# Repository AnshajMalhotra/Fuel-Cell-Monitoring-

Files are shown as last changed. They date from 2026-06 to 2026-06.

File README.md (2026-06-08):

# Project Seminar SS2025 — Fuel Cell Monitoring Board







A mixed-signal hardware and firmware project for monitoring fuel-cell voltage and current using a custom KiCad PCB, precision analog front-end, isolated SPI data path, 16-bit ADC acquisition, and ESP32-S3 based data processing.

This repository combines the complete PCB design files and embedded firmware developed for the **Project Seminar SS2025**. The board is intended to acquire fuel-cell electrical measurements, convert raw ADC data into physical voltage/current values, and stream the processed measurements to a host system over serial communication.

---

## Repository Description

**Short GitHub description:**

> KiCad + ESP32-S3 fuel-cell monitoring board with precision voltage/current sensing, 16-bit SPI ADC acquisition, digital isolation, and PlatformIO firmware for averaged serial data output.

---

## Project Overview

The project focuses on designing and implementing a fuel-cell monitoring board that can measure:

- Fuel-cell voltage
- Fuel-cell current
- ADC raw measurement values
- Averaged and calibrated output data

The system is built around a modular PCB design with separate schematic blocks for power, voltage measurement, current measurement, ADC conversion, data transmission, and microcontroller-side processing.

```mermaid
flowchart LR
    A[Fuel Cell Input] --> B[Voltage Measurement Stage]
    A --> C[Current Measurement Stage]
    B --> D[16-bit ADC]
    C --> D
    D --> E[Digital Isolation / SPI Interface]
    E --> F[ESP32-S3 Firmware]
    F --> G[Serial Output to Host]
```

---

## Key Features

- Custom PCB designed in **KiCad**
- Modular schematic structure for easier debugging and documentation
- Fuel-cell voltage sensing using a resistor divider and analog signal conditioning
- Fuel-cell current sensing using a shunt resistor and current-sense amplifier stage
- Precision voltage reference for ADC conversion
- SPI-based ADC communication
- Digital isolation for safer data transmission between analog and digital domains
- ESP32-S3 firmware using **PlatformIO** and the **Arduino framework**
- Timer-based sampling and averaging for stable readings
- Serial output in a simple host-readable format

---

## Hardware Architecture

| Block | Purpose | Related Files |
|---|---|---|
| Main KiCad Project | Central project configuration | `Project_Seminar_SS2025.kicad_pro` |
| PCB Layout | Physical board layout | `Project_Seminar_SS2025.kicad_pcb` |
| Root Schematic | Top-level schematic project | `Project_Seminar_SS2025.kicad_sch` |
| Power Supply | Power regulation and supply rails | `power.kicad_sch` |
| Voltage Measurement | Fuel-cell voltage sensing stage | `voltage_measure.kicad_sch`, `voltage_mea.kicad_sch` |
| Current Measurement | Shunt/current-sense stage | `current_measure.kicad_sch` |
| ADC Stage | ADC interface and analog conversion | `adc.kicad_sch`, `ADC_Main.kicad_sch` |
| Data Transmission | Isolated SPI / digital communication | `Data_Transmission_Main.kicad_sch` |
| Custom Symbols | Project-specific schematic symbols | `KiCad_Board_Design/MySymbols/` |
| Custom Footprints | Project-specific PCB footprints | `KiCad_Board_Design/MyFootprints/` |
| ERC Report | Electrical rules check output | `ERC.rpt` |

---

## Main Components Used

The design includes footprints/symbols for several important mixed-signal and embedded components, including:

- **ESP32-S3 DevKitC-1** — microcontroller and firmware execution platform
- **LTC2368IMS-16** — 16-bit ADC interface stage
- **LTC6655 4.096 V reference** — precision ADC reference
- **AD8410** — current-sense amplifier stage
- **LT6202** — analog signal conditioning / amplifier stage
- **ADuM4150BRIZ** — digital isolator for SPI communication
- **LT1761 / LT1762** — low-noise voltage regulators
- Custom connectors, jumpers, shunt resistor, and measurement terminals

---

## Firmware Overview

Firmware is located in:

```text
Board_Software/Fuel_Cell/
```

The ESP32-S3 firmware performs the following tasks:

1. Initializes serial communication at `115200 baud`
2. Configures SPI pins for ADC communication
3. Uses a hardware timer for periodic acquisition
4. Reads two 16-bit ADC channels from a 32-bit SPI transfer
5. Averages multiple samples for smoother measurements
6. Converts raw ADC values into voltage and current
7. Sends formatted readings to the host PC

### Firmware Pin Mapping

| Signal | ESP32-S3 Pin |
|---|---:|
| MOSI | GPIO 11 |
| MISO | GPIO 13 |
| SCK | GPIO 12 |
| SS / CS | GPIO 10 |
| CNV | GPIO 14 |
| BUSY | GPIO 9 |

### Serial Output Format

The firmware prints measurements in the following format:

```text
V:12.345,I:1.234
```

Where:

- `V` = calculated fuel-cell voltage in volts
- `I` = calculated fuel-cell current in amperes

---

## Measurement Conversion Logic

The firmware uses a 4.096 V ADC reference and 16-bit conversion range.

### Voltage Conversion

```cpp
adcInputVoltage = (rawValue / 65535.0) * 4.096;
fuelCellVoltage = adcInputVoltage * dividerRatio;
```

The voltage divider ratio is calculated from:

```cpp
R_TOTAL = 39000 + 2000;
R_BOTTOM = 3900 + 100;
dividerRatio = R_TOTAL / R_BOTTOM;
```

### Current Conversion

```cpp
senseAmpOutputVoltage = (rawValue / 65535.0) * 4.096;
shuntVoltage = senseAmpOutputVoltage / 20.0;
fuelCellCurrent = shuntVoltage / 0.008;
```

The current calculation depends on:

- Sense amplifier gain: `20`
- Shunt resistance used in firmware: `0.008 Ω`

> Update these constants if the final measured resistor values or amplifier gain differ from the prototype assumptions.

---

## Getting Started

### 1. Clone the Repository

```bash
git clone https://github.com/<your-username>/<your-repo-name>.git
cd <your-repo-name>
```

### 2. Open the PCB Design

Open the project file in KiCad:

```text
Project_Seminar_SS2025.kicad_pro
```

Recommended KiCad workflow:

1. Open the project in KiCad
2. Review the schematic hierarchy
3. Run ERC from the schematic editor
4. Open the PCB layout
5. Run DRC before manufacturing
6. Generate Gerber/drill files if the board is ready for fabrication

---

## Building and Uploading Firmware

### Prerequisites

Install:

- Visual Studio Code
- PlatformIO extension
- ESP32-S3 board support through PlatformIO
- USB driver for the ESP32-S3 board, if required

### Build Firmware

```bash
cd Board_Software/Fuel_Cell
pio run
```

### Upload Firmware

```bash
pio run --target upload
```

### Open Serial Monitor

```bash
pio device monitor -b 115200
```

Expected output:

```text
Fuel Cell Monitoring Board - Initializing...
Initialization Complete. Starting Data Acquisition.
V:12.345,I:1.234
```

---

## Repository Structure

```text
Project_Seminar_SS2025/
├── Project_Seminar_SS2025.kicad_pro       # Main KiCad project
├── Project_Seminar_SS2025.kicad_sch       # Top-level schematic
├── Project_Seminar_SS2025.kicad_pcb       # PCB layout
├── power.kicad_sch                        # Power supply design
├── current_measure.kicad_sch              # Current measurement circuit
├── voltage_measure.kicad_sch              # Voltage reference / measurement circuit
├── adc.kicad_sch                          # ADC schematic block
├── Data_Transmission_Main.kicad_sch       # Data transmission / isolation block
├── KiCad_Board_Design/
│   ├── MySymbols/                         # Custom KiCad symbols
│   └── MyFootprints/                      # Custom KiCad footprints
└── Board_Software/
    └── Fuel_Cell/
        ├── platformio.ini                 # PlatformIO configuration
        └── src/
            └── main.cpp                   # ESP32-S3 firmware
```

---

## Suggested GitHub Topics

Use these topics on GitHub to make the project easier to discover:

```text
kicad
pcb-design
esp32-s3
platformio
embedded-systems
fuel-cell
adc
spi
current-sensing
voltage-measurement
mixed-signal
arduino-framework
```

---

## Recommended Cleanup Before Publishing

Before pushing to GitHub, avoid committing generated or temporary files such as:

```text
.pio/
build/
*.bin
*.elf
*.map
*.o
*.d
*.bak
*.lck
Project_Seminar_SS2025-backups/
```

A cleaner repository will be smaller, easier to clone, and more professional for reviewers.

---

## Future Improvements

- Add calibration procedure for voltage and current measurements
- Add CSV logging or USB serial data parser on the host side
- Add OLED/display support for live local readings
- Add wireless transmission using Wi-Fi or BLE
- Add automated firmware tests for conversion functions
- Add final board render, schematic screenshots, and measurement results
- Generate Gerber files and attach manufacturing notes

---

## Author

**Anshaj Malhotra**  
M.Eng. Electrical and Information Engineering  
Hochschule Wismar

---

## License

No license has been selected yet. If this project is intended to be open-source, add a license such as MIT, Apache-2.0, or CERN-OHL depending on how you want others to use the hardware and software design.

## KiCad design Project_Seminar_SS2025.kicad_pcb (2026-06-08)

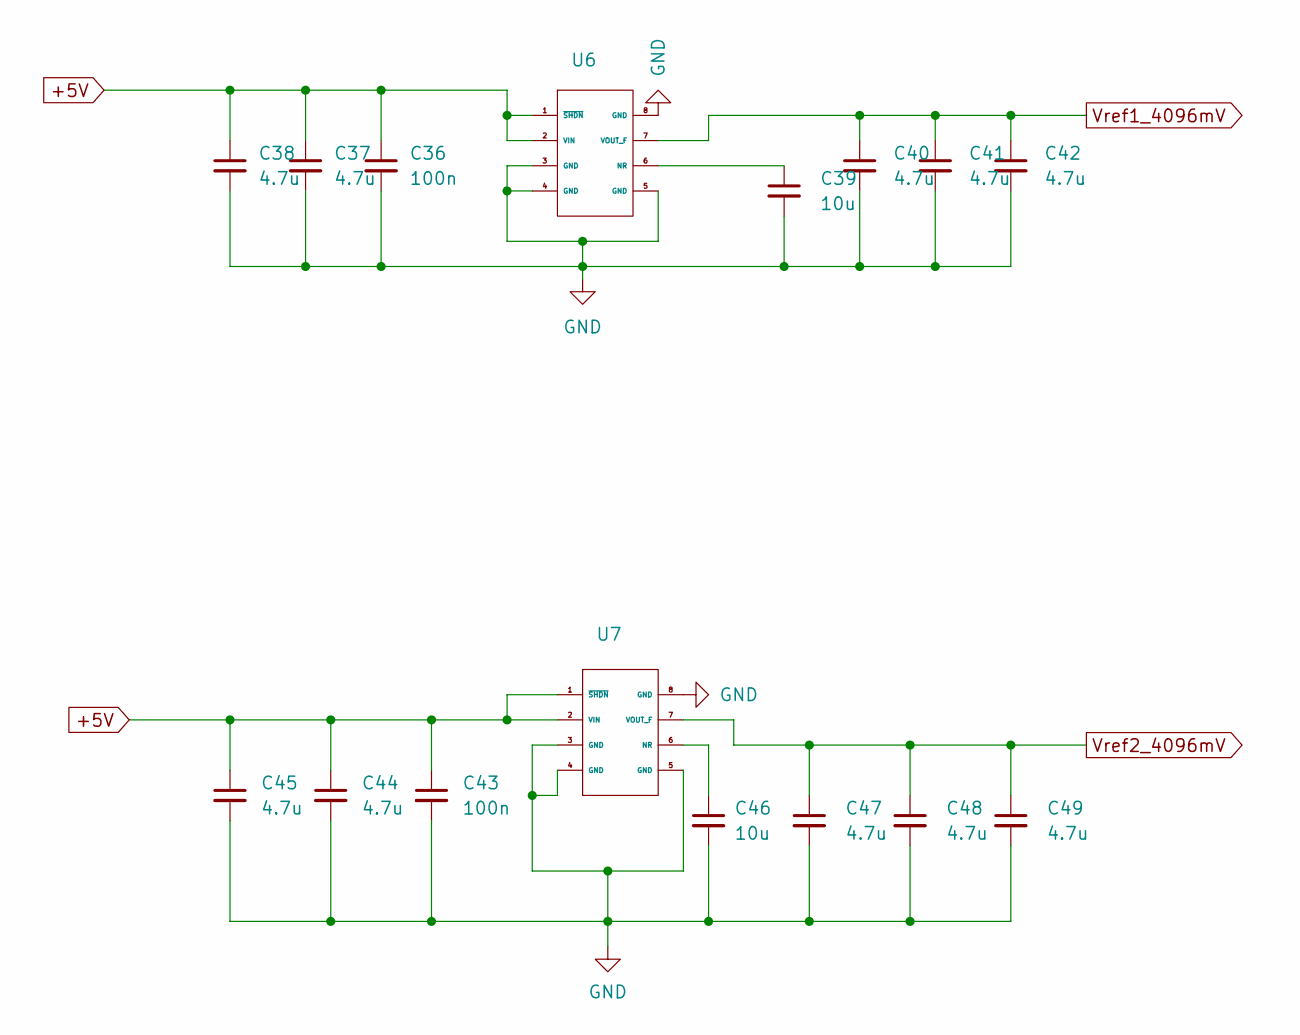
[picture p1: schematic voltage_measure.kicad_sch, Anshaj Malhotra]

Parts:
C36, C43: 100n; C_0201_0603Metric
C37, C38, C40, C41, C42, C44, C45, C47, C48, C49: 4.7u; C_0201_0603Metric
C39, C46: 10u; C_0201_0603Metric
U6, U7: LTC6655LNCHMS8-4.096#PBF

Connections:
+5V: C36.1, C37.1, C38.1, C43.1, C44.1, C45.1, U6.1 (~SHDN), U6.2 (VIN), U7.1 (~SHDN), U7.2 (VIN); also elsewhere on the board
GND: C36.2, C37.2, C38.2, C39.2, C40.2, C41.2, C42.2, C43.2, C44.2, C45.2, C46.2, C47.2, C48.2, C49.2, U6.3 (GND), U6.4 (GND), U6.5 (GND), U6.8 (GND), U7.3 (GND), U7.4 (GND), U7.5 (GND), U7.8 (GND); also elsewhere on the board
unnamed: C39.1, U6.6 (NR)
unnamed: C46.1, U7.6 (NR)
Vref1_4096mV: C40.1, C41.1, C42.1, U6.7 (VOUT_F); also elsewhere on the board
Vref2_4096mV: C47.1, C48.1, C49.1, U7.7 (VOUT_F); also elsewhere on the board

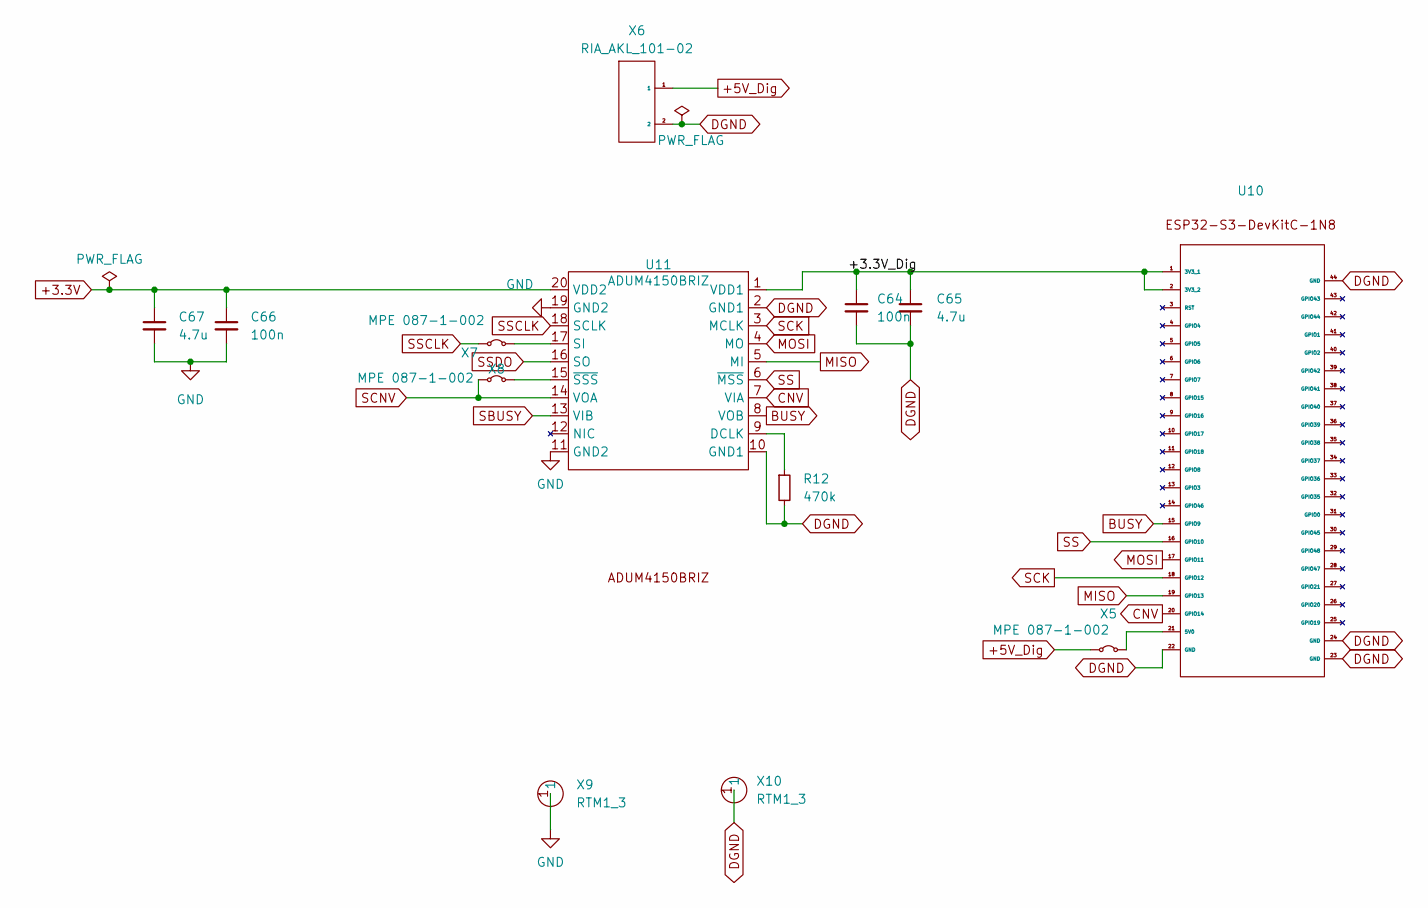
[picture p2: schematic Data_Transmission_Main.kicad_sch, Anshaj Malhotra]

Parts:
C64, C66: 100n; C_0201_0603Metric
C65, C67: 4.7u; C_0201_0603Metric
R12: 470k; R_0402_1005Metric
U10: ESP32
U11: ADUM4150BRIZ
X5, X7, X8: MPE 087-1-002; SolderJumper-2_P1.3mm_Bridged2Bar_Pad1.0x1.5mm
X6: RIA_AKL_101-02; AKL073-2
X9, X10: RTM1_3

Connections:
+3.3V: C66.1, C67.1, U11.20 (VDD2); also elsewhere on the board
+5V_Dig: X5.1 (A), X6.1
/Data transmission/+3.3V_Dig: C64.1, C65.1, U10.1 (3V3_1), U10.2 (3V3_2), U11.1 (VDD1)
BUSY: U10.15 (GPIO9), U11.8 (VOB)
CNV: U10.20 (GPIO14), U11.7 (VIA)
DGND: C64.2, C65.2, R12.2, U10.22 (GND), U10.23 (GND), U10.24 (GND), U10.44 (GND), U11.2 (GND1), U11.10 (GND1), X6.2, X10.1
GND: C66.2, C67.2, U11.11 (GND2), U11.19 (GND2), X9.1; also elsewhere on the board
MISO: U10.19 (GPIO13), U11.5 (MI)
MOSI: U10.17 (GPIO11), U11.4 (MO)
unnamed: U10.21 (5V0), X5.2 (B)
unnamed: R12.1, U11.9 (DCLK)
unnamed: U11.17 (SI), X7.2 (B)
unnamed: U11.15 (~SSS), X8.2 (B)
SBUSY: U11.13 (VIB); also elsewhere on the board
SCK: U10.18 (GPIO12), U11.3 (MCLK)
SCNV: U11.14 (VOA), X8.1 (A)
SS: U10.16 (GPIO10), U11.6 (~MSS)
SSCLK: U11.18 (SCLK), X7.1 (A)
SSDO: U11.16 (SO); also elsewhere on the board

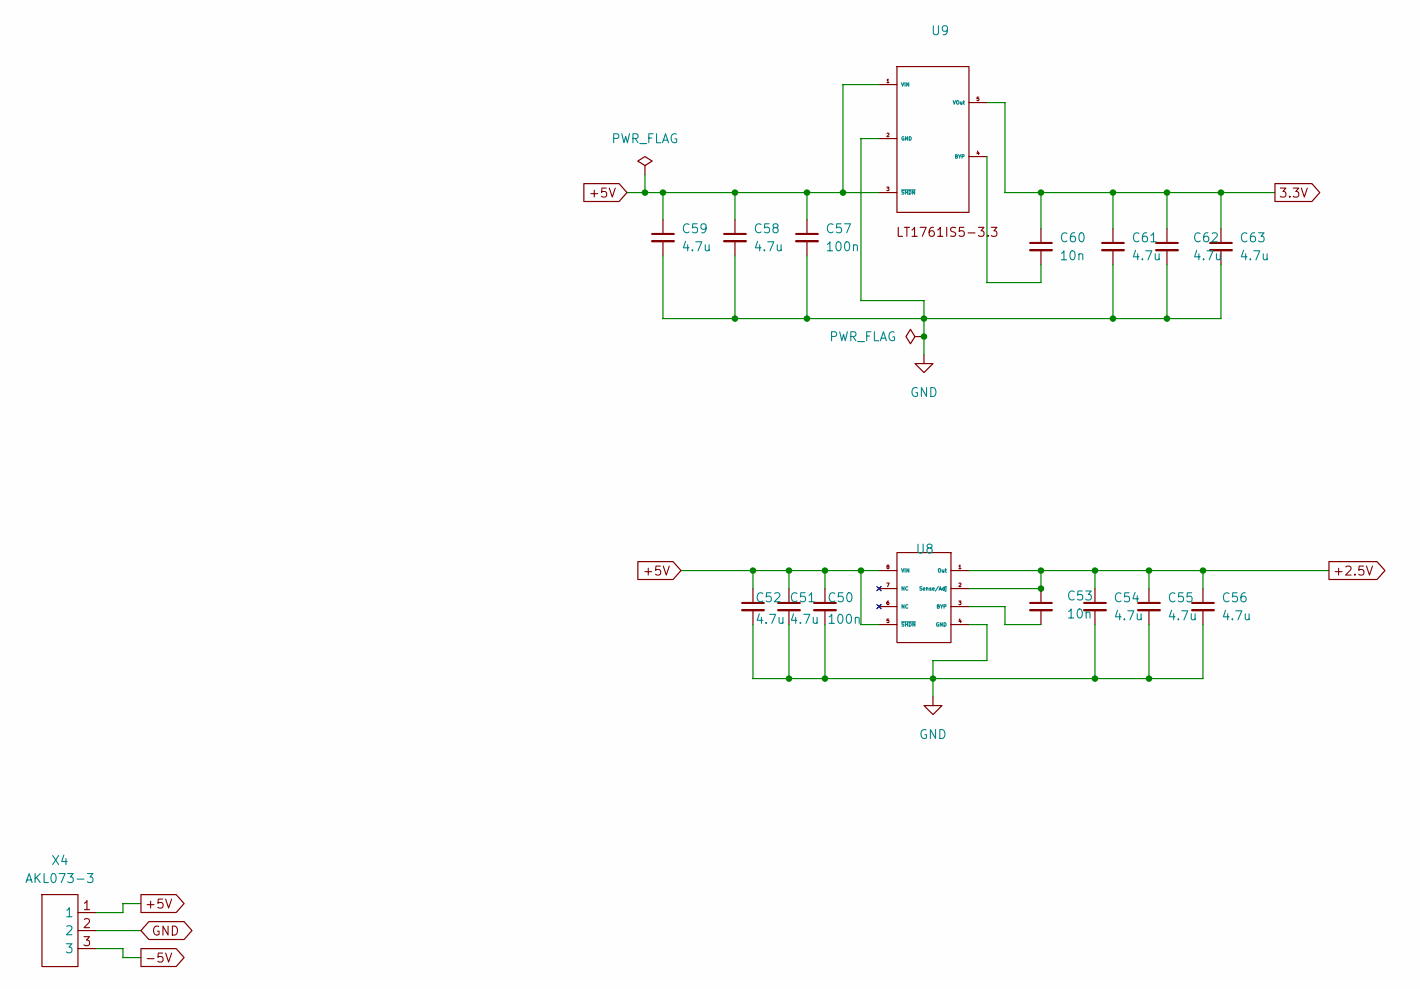
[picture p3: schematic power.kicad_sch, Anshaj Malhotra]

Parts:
C50, C57: 100n; C_0201_0603Metric
C51, C52, C54, C55, C56, C58, C59, C61, C62, C63: 4.7u; C_0201_0603Metric
C53, C60: 10n; C_0402_1005Metric
U8: LT1762EMS8-2v5
U9: LT1761IS5-3.3TRMPBF
X4: AKL073-3; Connector (AKL073-3)

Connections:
3.3V: C60.1, C61.1, C62.1, C63.1, U9.5 (VOut)
+2.5V: C53.1, C54.1, C55.1, C56.1, U8.1 (Out), U8.2 (Sense/Adj); also elsewhere on the board
+5V: C50.1, C51.1, C52.1, C57.1, C58.1, C59.1, U8.5 (~SHDN), U8.8 (VIN), U9.1 (VIN), U9.3 (~SHDN), X4.1; also elsewhere on the board
-5V: X4.3; also elsewhere on the board
GND: C50.2, C51.2, C52.2, C54.2, C55.2, C56.2, C57.2, C58.2, C59.2, C61.2, C62.2, C63.2, U8.4 (GND), U9.2 (GND), X4.2; also elsewhere on the board
unnamed: C53.2, U8.3 (BYP)
unnamed: C60.2, U9.4 (BYP)

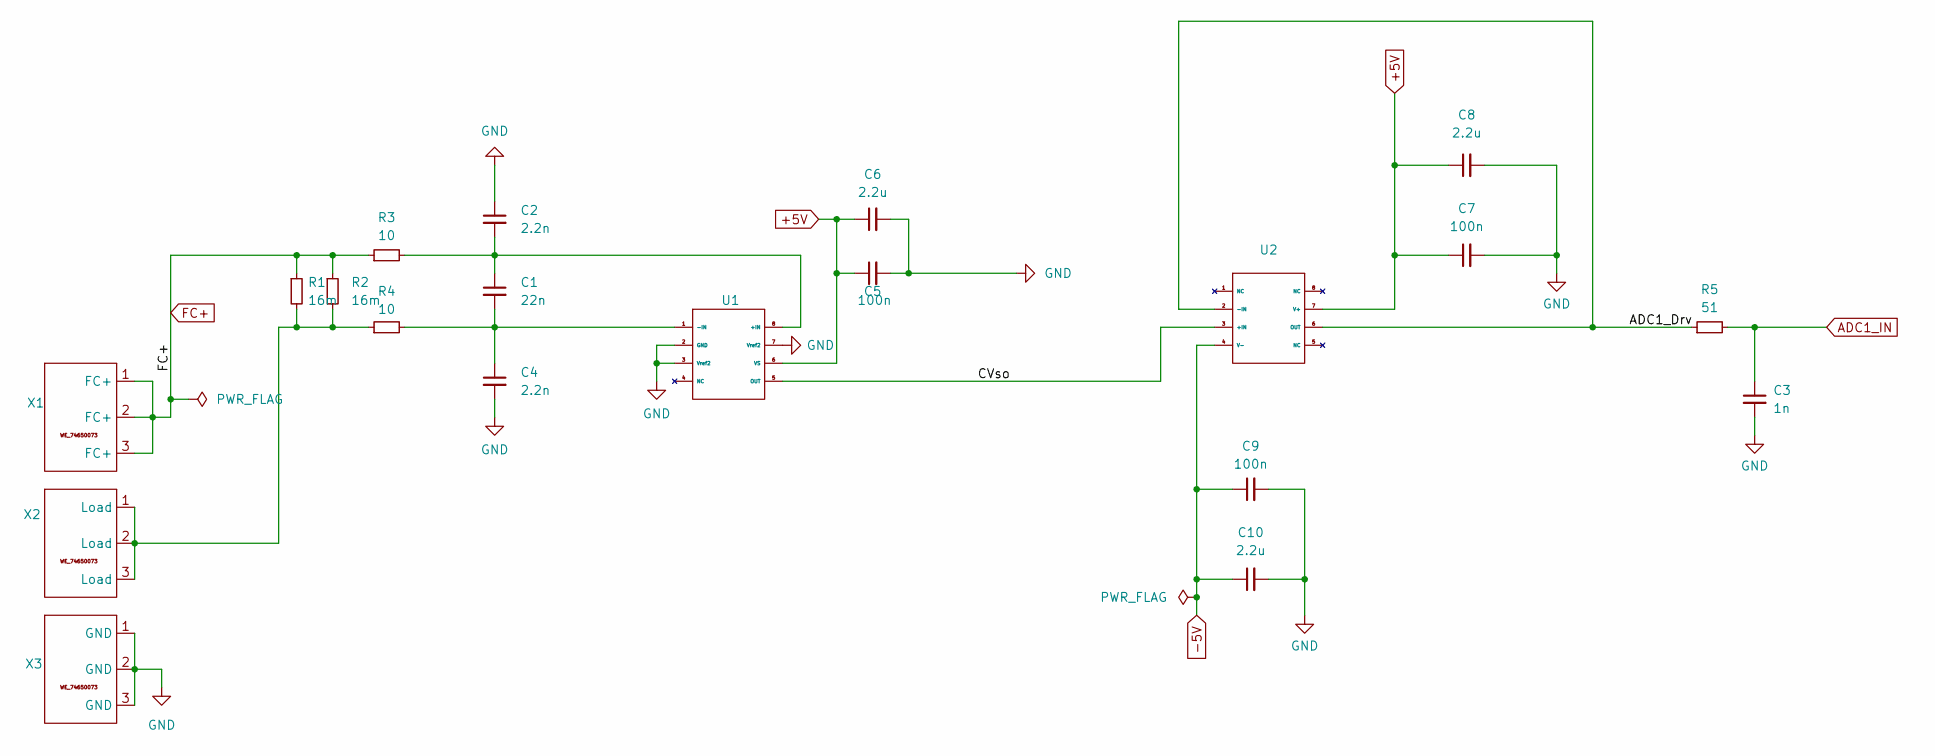
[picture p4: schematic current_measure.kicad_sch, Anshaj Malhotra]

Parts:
C1: 22n; C_0201_0603Metric
C2, C4: 2.2n; C_0201_0603Metric
C3: 1n; C_0201_0603Metric
C5, C7, C9: 100n; C_0201_0603Metric
C6, C8, C10: 2.2u; C_0201_0603Metric
R1, R2: 16m; R_2512_6332Metric
R3, R4: 10; R_0603_1608Metric
R5: 51; R_0603_1608Metric
U1: AD8410ABWRZ
U2: LT6202IS8
X1, X2, X3: WE_74650073

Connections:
+5V: C5.1, C6.1, C7.1, C8.1, U1.6 (VS), U2.7 (V+); also elsewhere on the board
-5V: C9.1, C10.1, U2.4 (V-); also elsewhere on the board
/current_measure/ADC1_Drv: R5.1, U2.2 (-IN), U2.6 (OUT)
/current_measure/CVso: U1.5 (OUT), U2.3 (+IN)
ADC1_IN: C3.1, R5.2; also elsewhere on the board
FC+: R1.1, R2.1, R3.1, X1.1 (FC+), X1.2 (FC+), X1.3 (FC+); also elsewhere on the board
GND: C2.1, C3.2, C4.2, C5.2, C6.2, C7.2, C8.2, C9.2, C10.2, U1.2 (GND), U1.3 (Vref2), U1.7 (Vref2), X3.1 (GND), X3.2 (GND), X3.3 (GND); also elsewhere on the board
unnamed: R1.2, R2.2, R4.1, X2.1 (Load), X2.2 (Load), X2.3 (Load)
unnamed: C1.1, C2.2, R3.2, U1.8 (+IN)
unnamed: C1.2, C4.1, R4.2, U1.1 (-IN)

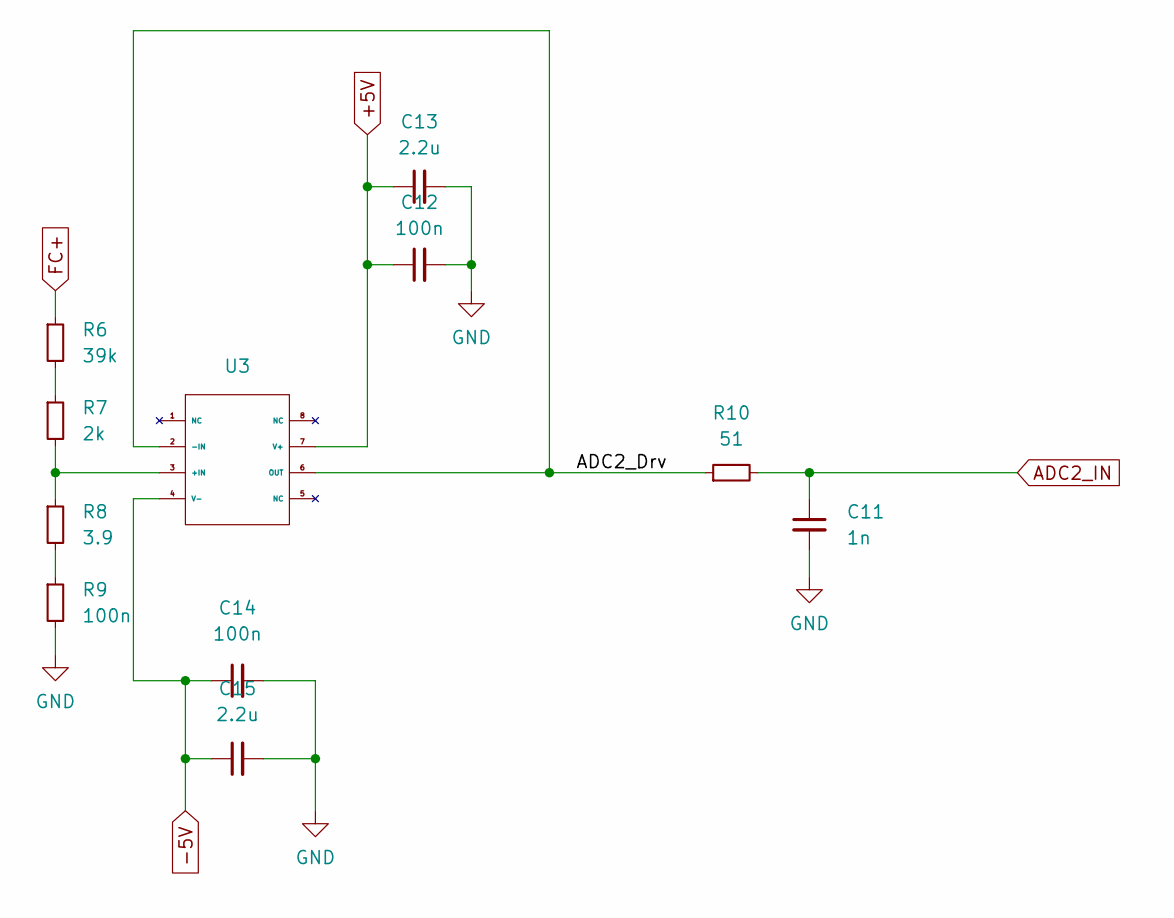
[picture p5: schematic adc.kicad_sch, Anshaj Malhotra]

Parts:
C11: 1n; C_0201_0603Metric
C12, C14: 100n; C_0201_0603Metric
C13, C15: 2.2u; C_0201_0603Metric
R6: 39k; R_0603_1608Metric
R7: 2k; R_0603_1608Metric
R8: 3.9; R_0603_1608Metric
R9: 100n; R_0603_1608Metric
R10: 51; R_0603_1608Metric
U3: LT6202IS8

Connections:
+5V: C12.1, C13.1, U3.7 (V+); also elsewhere on the board
-5V: C14.1, C15.1, U3.4 (V-); also elsewhere on the board
/voltage_measurement/ADC2_Drv: R10.1, U3.2 (-IN), U3.6 (OUT)
ADC2_IN: C11.1, R10.2; also elsewhere on the board
FC+: R6.1; also elsewhere on the board
GND: C11.2, C12.2, C13.2, C14.2, C15.2, R9.2; also elsewhere on the board
unnamed: R6.2, R7.1
unnamed: R8.2, R9.1
unnamed: R7.2, R8.1, U3.3 (+IN)

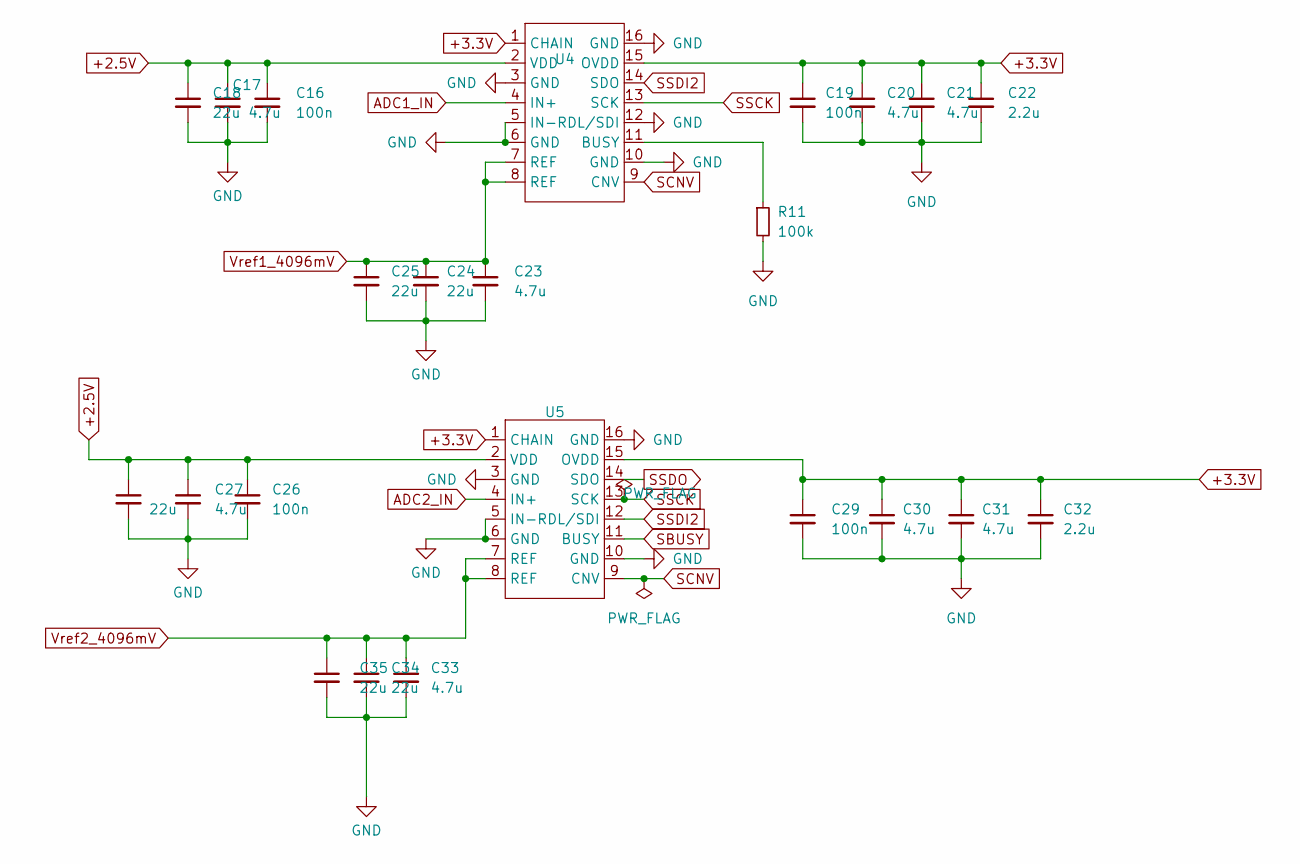
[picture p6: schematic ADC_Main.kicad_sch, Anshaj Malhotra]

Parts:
C16, C19, C26, C29: 100n; C_0201_0603Metric
C17, C20, C21, C23, C27, C30, C31, C33: 4.7u; C_0201_0603Metric
C18: 22u; C_0201_0603Metric
C22, C32: 2.2u; C_0201_0603Metric
C24, C25, C28, C34, C35: 22u; C_0805_2012Metric
R11: 100k; R_0603_1608Metric
U4, U5: LTC2368IMS-16

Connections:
+2.5V: C16.1, C17.1, C18.1, C26.1, C27.1, C28.1, U4.2 (VDD), U5.2 (VDD); also elsewhere on the board
+3.3V: C19.1, C20.1, C21.1, C22.1, C29.1, C30.1, C31.1, C32.1, U4.1 (CHAIN), U4.15 (OVDD), U5.1 (CHAIN), U5.15 (OVDD); also elsewhere on the board
ADC1_IN: U4.4 (IN+); also elsewhere on the board
ADC2_IN: U5.4 (IN+); also elsewhere on the board
GND: C16.2, C17.2, C18.2, C19.2, C20.2, C21.2, C22.2, C23.2, C24.2, C25.2, C26.2, C27.2, C28.2, C29.2, C30.2, C31.2, C32.2, C33.2, C34.2, C35.2, R11.2, U4.3 (GND), U4.5 (IN-), U4.6 (GND), U4.10 (GND), U4.12 (RDL/SDI), U4.16 (GND), U5.3 (GND), U5.5 (IN-), U5.6 (GND), U5.10 (GND), U5.16 (GND); also elsewhere on the board
unnamed: R11.1, U4.11 (BUSY)
SBUSY: U5.11 (BUSY); also elsewhere on the board
SCNV: U4.9 (CNV), U5.9 (CNV)
SSCK: U4.13 (SCK), U5.13 (SCK)
SSDI2: U4.14 (SDO), U5.12 (RDL/SDI)
SSDO: U5.14 (SDO); also elsewhere on the board
Vref1_4096mV: C23.1, C24.1, C25.1, U4.7 (REF), U4.8 (REF); also elsewhere on the board
Vref2_4096mV: C33.1, C34.1, C35.1, U5.7 (REF), U5.8 (REF); also elsewhere on the board

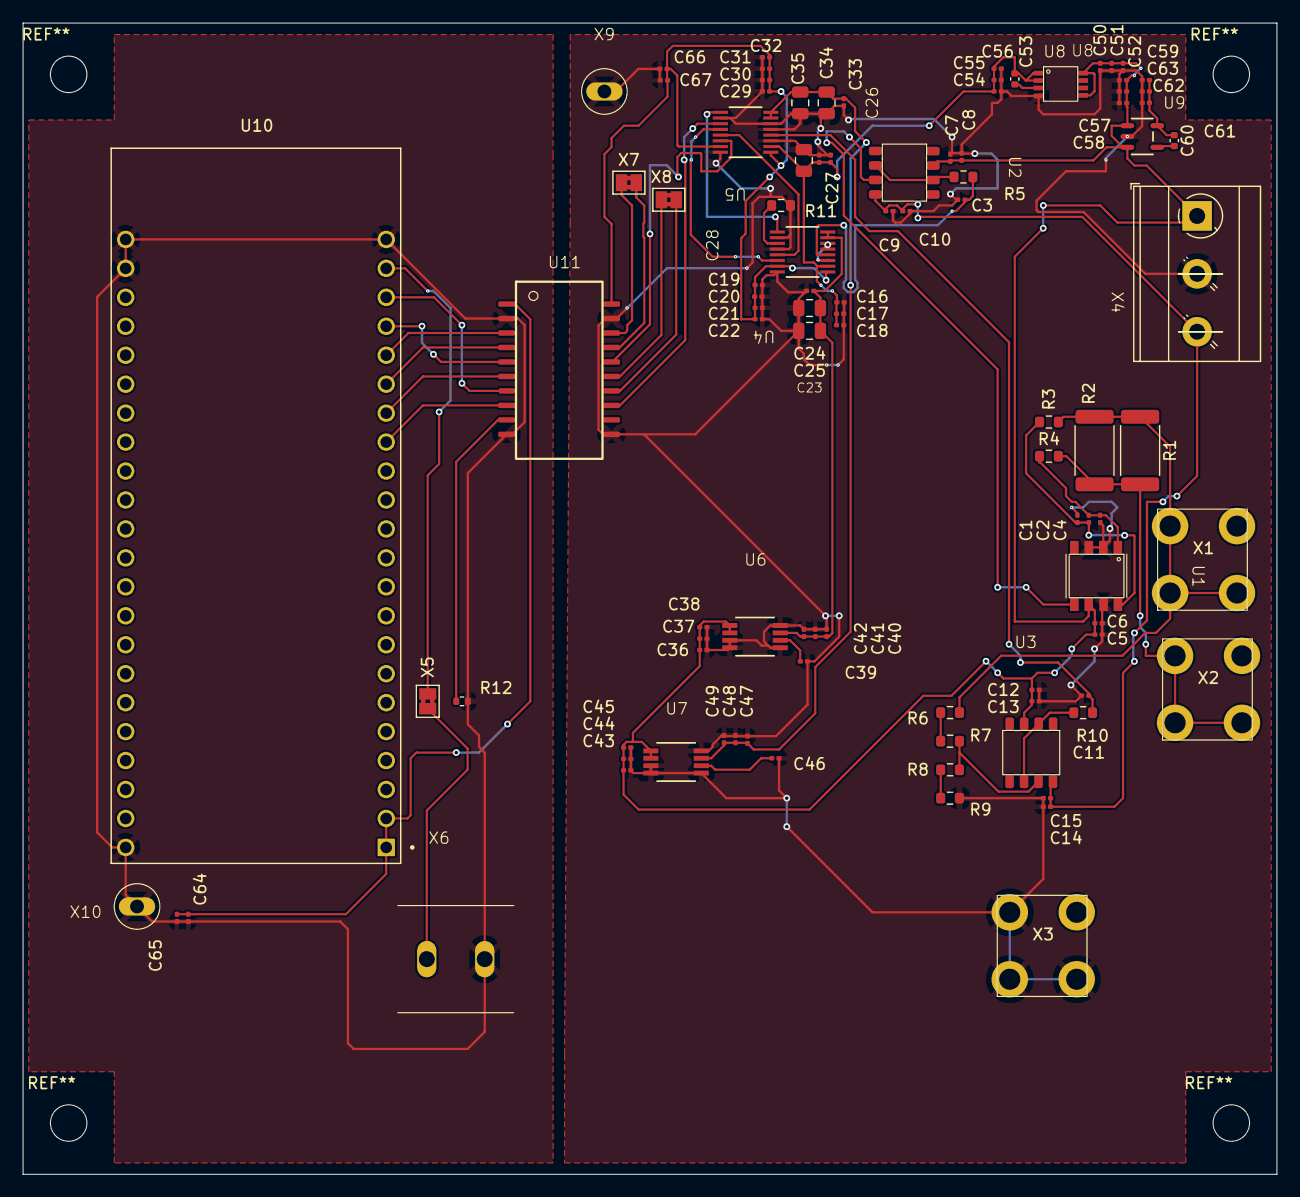
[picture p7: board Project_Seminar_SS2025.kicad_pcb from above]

Board: 2 copper layers, 110.0 x 101.0 mm, 100 parts (0 on the bottom side), 45 nets.
